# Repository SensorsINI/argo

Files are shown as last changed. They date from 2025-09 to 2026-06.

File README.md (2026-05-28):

# Argo Autonomous Sailboat

An autonomous sailboat system based on Dragonforce 65 hull, running on Orange Pi Zero 2W with ROS2. The system includes comprehensive sensor integration, autonomous navigation, and safety monitoring.

[argo freecad 3d.webm](https://github.com/user-attachments/assets/29d93eb4-6dfb-44b6-a583-b5699d12e7a1)

## News
- **May 2026:** After ignominious series of problems at CCNW with cabling, water leaks, GPS and many other issues and only 30m of actual seawater sailing, came back to INI to fix these problems. Now IMU is working, GPS is working, dashboard has map display, there are new cable glands and a new hull that has been air-pressure tested for leaks. We are ready now for water trials again.
- **Mar 2026:** Version 4 of argo PCB with bug fixes, wind sensor on separate I2C bus, and new buzzer. Version 3 of the wind sensor PCB with RGBW LED controller. See [Argo2: Robot Sailboat](https://docs.google.com/presentation/d/15X9GgjOmHowyNMNPRnduzyOgwyVcawP_Lhy54-Hc9cc/edit?usp=sharing) slides presented online at [Embodied Intelligence Conference](https://ei26.embodied-intelligence.org/) 20 March 2026.
- **Feb 2026:** Updated [wind sensor design PCB and housing](pcb/WindSensor/WindSensor-rev1/) complete. 3D parts for wind sensor I2C cable and mast step up completed and printed.
- **Jan 2026:** [Argo main PCB version 3](pcb/argo-v9-stable/argo-v9-stable-rev3/) completed and seems fully functional with no surgery needed.
- **Aug-Dec 2025:** Intense development of new [Argo PCB](pcb/) and [ROS2 software framework](nodes/). System services developed (see [`power_control/argo_power_control.py`](power_control/argo_power_control.py) and [`launch/argo_lifecycle_manager.py`](launch/argo_lifecycle_manager.py)) along with robust [lifecycle management](launch/argo_lifecycle_manager.py) and [battery/power control](power_control/argo_power_control.py).
- **Oct-Nov 2025:** Developed first version of [Argo simulator](simulator/).  
  - See [simulator/sailboat-playground/README.md](simulator/sailboat-playground/README.md) for usage and architecture.  
  - Additional docs: [Simulation Guide](docs/SIMULATION.md), [Debug Simulation Guide](docs/README-debug-simulation.md)  

## Installation

Pick **Argo (boat)** or **Host (PC)** below. ROS 2 **must match your Ubuntu LTS**: 22.04 (Jammy) → **Humble**; 24.04 (Noble) → **Jazzy**. Use the official [ROS 2 Ubuntu (deb) install](https://docs.ros.org/en/jazzy/Installation/Ubuntu-Install-Debs.html) page that corresponds to your ROS release.

### Argo (boat — Orange Pi Zero 2W)

On the robot, the stack targets **Ubuntu 22.04–based** Armbian and **ROS 2 Humble**. Bring up I²C/UART/PWM overlays, the radio/servo kernel module, Python dependencies, systemd services, and power control as described in the [launch](launch/) tree.

```bash
cd ~/argo   # or your clone path
sudo apt update && sudo apt upgrade -y
# Install ROS 2 Humble (.deb), then in each shell you use for builds:
#   source /opt/ros/humble/setup.bash

make install-all          # Python deps + optional hardware (see Makefile / messages)
make install-argo-cli
source ~/.bashrc
make -C launch install    # install systemd units; enable per docs
```

#### First-time SD card and hardware bring-up

**1. Flash Orange Pi OS** using Orange Pi Imager or equivalent.

**2. Initial system setup**

```bash
sudo apt update && sudo apt upgrade -y
sudo apt install python3-pip python3-dev build-essential
sudo apt install i2c-tools device-tree-compiler git
sudo apt install ros-humble-desktop
```

**3. Clone repository**

```bash
cd /home/orangepi
git clone https://github.com/SensorsINI/argo.git
cd argo
```

**4. Python and ROS helpers**

```bash
make install-python-deps   # requirements.txt on the boat
# If needed:
sudo apt install python3-rclpy python3-std-msgs python3-geometry-msgs
```

**5. Hardware configuration**

Edit `/boot/orangepiEnv.txt` and add overlays:

```
overlays=pi-i2c0 disable-uart0 ph-uart5 pi-pwm2 pi-pwm4
user_overlays=argo_radio_servo_overlay
```

Build and load the PWM capture module:

```bash
cd ~/argo/nodes/pwm_capture_module
make all
sudo modprobe argo_radio_servo_module   # or reboot
```

Add your user to hardware groups:

```bash
sudo usermod -a -G i2c,dialout $USER
# log out and back in
```

**6. Verify**

```bash
sudo i2cdetect -y 0
lsmod | grep argo
ls -la /sys/kernel/argo_radio_servo/
sudo cat /dev/ttyS5
```

**7. CLI and services**

```bash
make install-argo-cli && source ~/.bashrc
make -C launch install
sudo systemctl daemon-reload
sudo systemctl enable argo_launch.service
```

### Host (simulation, Foxglove, remote monitoring)

Use this on a **laptop or workstation** for **local simulation** (`asim`), **Foxglove Studio** (same Wi‑Fi, VPN, or SSH tunnel), log playback, and shore-side scripts. The boat still runs ROS 2 on the Orange Pi; your host subscribes/records like any ROS 2 client. **LoRa** is a boat link—the monitoring machine uses normal network ROS 2 or recorded bags unless you run a separate LoRa gateway stack.

**Prerequisites:** Ubuntu **22.04** or **24.04** (see mapping to Humble/Jazzy above), `git`, `make`, `sudo`, and network access for `apt`.

**One-shot bootstrap (Ubuntu 22.04 or 24.04):**

```bash
cd /path/to/argo
make host-setup
source ~/.bashrc                     # reload Argo dotfiles in this terminal (or open a new tab)
# Dotfiles auto-source the first ROS found under /opt/ros (jazzy, iron, humble, rolling) when ROS_DISTRO is unset.

source .venv/bin/activate            # optional; pip tooling (argcomplete, pyglet, …)
asim
```

If a command in **this** terminal cannot find `rclpy` or `ros2` right after `host-setup`, the ROS underlay is not loaded yet: run `source ~/.bashrc` (as above), or explicitly `source /opt/ros/humble/setup.bash` / `source /opt/ros/jazzy/setup.bash` matching your install.

`make host-setup` **refuses to run on Orange Pi** (use `make install-all` on the boat). It:

- Adds **`/etc/apt/sources.list.d/ros2-latest.list`** only if no file already references **packages.ros.org/ros2/ubuntu** (avoids a second `Signed-By` if you installed ROS 2 from the official doc first)  
- Installs **`ros-<distro>-ros-base`** when `/opt/ros/<distro>` is absent (Jammy → `humble`, Noble → `jazzy`, or override with `ROS_DISTRO=`)  
- Runs **`make install-deps`** (single `apt-get update`, then Argo’s ROS .deb set, Foxglove bridge, MCAP storage)  
- Runs **`make setup-venv`** (creates `.venv` with **uv** if available, otherwise `python3 -m venv`, and installs **`requirements-host.txt`**) then **`make install-python-deps`** (same host requirements file again into `.venv`—idempotent on a PC)  
- Runs **`make install-argo-cli`** and **`make submodule-init`** (`install-argo-cli` appends **`source <repo>/dotfiles/bashrc`** to **`~/.bashrc`**; that file auto-sources **`/opt/ros/<distro>/setup.bash`** when **`ROS_DISTRO`** is not already set)  

**Tab completion (optional):** Global argcomplete is **not** installed automatically on every shell (keeps login fast). After `host-setup`, run once: `activate-global-python-argcomplete3 --user` or `activate-global-python-argcomplete --user`, or see [dotfiles/README.md — Tab Completion Setup](dotfiles/README.md#tab-completion-setup).

Force a distro explicitly, e.g. on non-LTS or mixed images:

```bash
make host-setup ROS_DISTRO=jazzy
```

If **`apt-get update`** reports **conflicting Signed-By** for `packages.ros.org/ros2/ubuntu`, you have two ROS 2 source files—keep one. For example, if you already used the official installer, remove Argo’s duplicate and refresh: `sudo rm -f /etc/apt/sources.list.d/ros2-latest.list && sudo apt-get update`.

`install-ros2-apt-repo` checks for an existing ROS 2 source with **`sudo grep`** because some `sources.list.d` entries are **root-only**; without that, Make could miss your working repo and add a second file.

**Foxglove:** with ROS sourced on the machine that runs the bridge, start `ros2 run foxglove_bridge foxglove_bridge` and connect from [Foxglove Studio](https://foxglove.dev/) to `ws://<that-host-ip>:8765`.

### Makefile targets and shell aliases (reference)

- `make host-setup` — **host-only** full bootstrap (see above)  
- `make install-deps` — ROS packages for the current `ROS_DISTRO` (Foxglove, MCAP, …)  
- `make install-python-deps` — robot uses `requirements.txt`; host uses `requirements-host.txt` (prefers `.venv` if present)  
- `make install-hardware` — PWM module (boat)  
- `make install-all` — boat-oriented dependency + hardware path  
- `make -C launch …` — lifecycle systemd helpers  

After `make install-argo-cli`, common aliases include `al` / `aq` / `ars` (services), `as` / `asq` (status), `asim` (local sim), `ar` / `ac` (recording), `alog`, `ah`. Run `make help` and see [dotfiles/](dotfiles/).

## System Overview

The Argo system consists of multiple ROS2 nodes that work together to provide autonomous sailing capabilities:

- **Sensor Nodes**: GPS (u-blox NEO-M9N), IMU ([Adafruit BNO085](https://www.adafruit.com/product/4754)), Wind sensors (3x Sensirion SDP3x), Battery/Water monitoring
- **Control Interface**: PWM capture for radio control and servo output  
- **Autonomous Control**: Navigation and sail trimming algorithms
- **Safety Systems**: Manual override, battery monitoring, water intrusion detection

### Demo Video
See the Argo autonomous sailboat in action at the 2024 CCNW (before current waterproofing and PCB developements): [Argo Sailboat Demo](https://youtu.be/tjC1262BsCY?si=1GFPk1QcOqpzw8h2)

Argo Autonomous Sailboat

## Hardware Platform
The main PCB design for Argo is available in the [pcb/](pcb/) folder. The latest board version is [rev4](pcb/argo-v9-stable/argo-v9-stable-rev4/), which contains the current sailboat control and sensor interface design.

- **Orange Pi Zero 2W** (Allwinner H618 SoC)
- **GPS**: u-blox NEO-M9N via UART5 (/dev/ttyS5)
- **IMU**: [Adafruit BNO085](https://www.adafruit.com/product/4754) 9-DOF Orientation IMU via I2C0 (0x4a)
- **Wind Sensor**: 3x Sensirion SDP3x differential pressure sensors via I2C0 (0x21, 0x22, 0x23). This PCB includes an RGBW LED and its I2C controller PCA9632 at individual address 0x62 (0x70 is LED All Call).  
  - **Design files:** See [`pcb/WindSensor/WindSensor-rev1/`](pcb/WindSensor/WindSensor-rev1/) directory for full hardware schematics, layout, and BOM.
- **ADC**: MAX11612 for battery/water sensing via I2C0 (0x34)
- **Environment**: SHT45 temperature/humidity via I2C0 (0x44)
- **PWM I/O**: Custom kernel module for radio control and servo interfaces with high impedance safety mode
- **LORA**: Long range radio based on RA-01 radio module from ai-thinker.com using SX1276 LORA chip

### Hardware Replacement and MAC Address Cloning

The Argo system is designed to handle frequent SBC hardware replacements (due to damage) while maintaining network identity. The WiFi MAC address is frozen to a consistent value (`c8:26:e2:6c:58:ba`) stored in `network/ARGO_MAC_ID.txt` and committed to git. This ensures:

- **Network Stability**: Same MAC address across hardware changes maintains network access (uzh-iot, ZeroTier, tobi-wlan)
- **SD Card Portability**: Same SD card works seamlessly with different SBC hardware
- **Automatic Configuration**: Run `make freeze-mac-address` after hardware replacement to restore network identity

See [Network Improvements Documentation](network/README.md#mac-address-cloning-hardware-replacement) for details.

### Servo Control Hardware

The Argo system uses a shared control circuit design that allows both radio control and autonomous software control of servos through a fail-safe high impedance switching mechanism:

#### Stock DF65 V6 (2018) Servo Configuration
- **Sail Winch Servo**: Joysway #880545
  - Type: Standard sail winch servo with high-precision plastic gears
  - Operating voltage: 4.8V to 6.0V
  - PWM frequency: 1520μs/50Hz
  - **Input impedance: 12kΩ** (measured)
  - **Circuit resistor: 3.3kΩ** (optimized for proper signal level)

- **Rudder Servo**: Joysway #881504  
  - Type: Digital metal gear servo
  - Operating voltage: 4.8V to 6.0V
  - PWM frequency: 1520μs/330Hz
  - **Input impedance: 400kΩ** (measured)
  - **Circuit resistor: 10kΩ** (standard value works well)

#### Shared Control Circuit Design
The hardware implements a fail-safe shared control circuit where:

1. **High Impedance Safety Mode**: When PWM outputs are disabled (high impedance), radio control signals pass through resistors directly to servo inputs
2. **Software Control Mode**: When PWM outputs are enabled, software generates servo control signals
3. **Voltage Divider Considerations**: Resistor values are optimized based on servo input impedance:
   - Sail servo: 3.3V × (12kΩ / (3.3kΩ + 12kΩ)) = 2.6V (adequate signal level)
   - Rudder servo: 3.3V × (400kΩ / (10kΩ + 400kΩ)) = 3.2V (excellent signal level)

#### GPIO Pin Assignments (Orange Pi Zero 2W)
- **PI11 (Pin 7)**: Radio Rudder Input - GPIO input with interrupt capability
- **PI13 (Pin 26)**: Radio Sail Input - GPIO input with interrupt capability  
- **PI12 (Pin 33)**: Servo Rudder Output - PWM2 channel, high impedance when disabled
- **PI14 (Pin 16)**: Servo Sail Output - PWM4 channel, high impedance when disabled

This design ensures **radio control always works** when software is not running, providing maximum safety for autonomous sailboat operation.

## ROS2 Software Architecture
```mermaid
flowchart TB
  subgraph OUTPUTS[Output Nodes]
    RSR[rudder_sail_radio primary actuation output]
    LORA[lora long range communications]
  end

  CTRL[controller primary decision and control logic]

  subgraph SAFETY[Critical Safety Services]
    BW[battery_water critical]
    LA[launch critical]
  end

  subgraph SENSORS[Sensor Input Layer]
    GPS[gps]
    IMU[imu BNO085]
    ANEM[anem]
  end

  VR[Visualization and Recording]

  GPS --> CTRL
  IMU --> CTRL
  ANEM --> CTRL
  CTRL --> RSR

  BW --> LA
  LA --> CTRL

  CTRL --> VR

  CTRL -.-> LORA
```

### Project Organization

The Argo system follows a modular ROS2 architecture with clear separation of concerns:

**Directory Structure:**
- **`nodes/`** - Individual ROS2 nodes (Python-based sensor interfaces)
- **`launch/`** - Lifecycle management, systemd services, and launch configurations
- **`power_control/`** - Power management system (separate ROS2 package)
- **`foxglove/`** - Visualization layouts for Foxglove Studio
- **`simulator/`** - Sailboat simulation submodule (sailboat-playground)

## Other READMEs

### Core System Documentation
- [**Systemd Services Architecture**](docs/README-services.md) - Service dependencies, boot sequence, and troubleshooting
- [**Network Improvements**](network/README.md) - WiFi reconnection, MAC address cloning, and NetworkManager configuration
- [**ZeroTier VPN Setup**](docs/README_zerotier.md) - ZeroTier VPN configuration, SSH access, and network management
- [**Power Control System**](power_control/README.md) - Power button, LED control, and graceful shutdown
- [**Systemd Integration**](launch/README.md) - Launch system and lifecycle management
- [**Shutdown Fixes**](docs/SHUTDOWN_FIXES.md) - Shutdown procedure fixes and improvements
- [**LED Status Guide**](docs/ARGO_LED_STATUS_GUIDE.md) - LED status display and hatch cover indicators

### Development & Simulation
- [**Simulation System Overview**](simulator/README.md) - Sailboat simulation framework
- [**Simulation Documentation**](docs/SIMULATION.md) - Simulation setup and usage
- [**Debug Simulation**](docs/README-debug-simulation.md) - Debugging simulation issues

### Hardware & Configuration
- [**I2C Configuration**](docs/README-i2c.md) - I2C bus setup and troubleshooting
- [**LoRa (onboard ↔ shore)**](docs/README-lora-to-shore.md) - SX1276 / Waveshare hardware, link parameters, packet header
- [**IMU BNO085**](docs/README-imu-bno085.md) - C++ driver, Python bridge, calibration, `argo_bno085` service
- [**Thermal monitoring (SBC)**](docs/README-thermal-monitoring.md) - Orange Pi GPU/CPU/DDR temperature logging (`argo_thermal_monitor`)
- [**Watchdog Configuration**](docs/README-watchdog.md) - Watchdog setup for Orange Pi Zero 2W
- [**CPU Frequency Tuning**](docs/README-cpufreq-tuning-service.md) - CPU governor configuration
- [**Battery & Power Monitoring**](docs/README-battery-power.md) - Battery monitoring system
- [**Battery Panel Setup**](docs/BATTERY_PANEL_SETUP.md) - Battery panel configuration
- [**SD Card Backup**](docs/README-sd-card-backup.md) - SD card backup procedures
- [**DVFS Userspace Access**](docs/dvfs_userspace_access.md) - Dynamic voltage and frequency scaling

### Visualization & Analysis
- [**Foxglove Visualization**](foxglove/README.md) - Real-time visualization setup
- [**Foxglove Debugging**](docs/FOXGLOVE_DEBUGGING.md) - Debugging Foxglove issues
- [**Foxglove Joystick Setup**](docs/FOXGLOVE_JOYSTICK_SETUP.md) - Joystick control configuration
- [**3D Visualization**](docs/README-3d-visualization.md) - 3D visualization configuration
- [**Visualization Marker Persistence**](docs/VISUALIZATION_MARKER_PERSISTENCE.md) - Marker persistence in visualization
- [**Adding Sailing Maps**](docs/README-adding-sailing-maps.md) - Map integration guide
- [**Maps Documentation**](maps/README-maps.md) - Sailing area maps

### Remote Access & Interface
- [**Remote Desktop VNC**](docs/README_REMOTE_DESKTOP_VNC.md) - VNC remote desktop setup
- [**Web Dashboard**](docs/WEB_DASHBOARD_README.md) - Mobile-friendly web interface

### CLI & User Interface
- [**CLI Completion**](docs/CLI_COMPLETION.md) - Command-line completion setup
- [**Completion Quickstart**](docs/COMPLETION_QUICKSTART.md) - Quick start guide for CLI completion
- [**MOTD Customization**](docs/MOTD_CUSTOMIZATION.md) - Message of the day customization

### Additional Resources
- [**ROS2 Nodes**](nodes/README.md) - Node documentation and configuration
- [**Scripts**](scripts/README.md) - Utility scripts documentation
- [**Dotfiles Setup**](dotfiles/README.md) - CLI aliases and shell configuration
- [**Persistent Logging**](docs/README-persistent-logging.md) - Logging configuration

### Simulation Support

Argo includes comprehensive simulation support for development and testing:

**Local Simulation:**
- Runs simulator directly on Orange Pi
- Uses sailboat-playground or mock simulator
- Excludes conflicting hardware nodes (GPS, IMU, anemometer, radio control)
- Perfect for algorithm development and testing

**Remote Simulation:**
- Offloads CPU-intensive simulation to remote machine
- SSH tunnel for ROS2 communication
- Centralized configuration management
- Ideal for resource-constrained environments

**Quick Start:**
```bash
# Local simulation
python3 launch/argo_lifecycle_manager.py simulate_local

# Remote simulation (requires setup)
python3 launch/argo_lifecycle_manager.py simulate_remote

# Or use helper scripts (equivalent flow):
./scripts/remote_simulator_tunnel.sh &
python3 scripts/remote_simulator_launch.py &
./scripts/launch_simulator_remote.sh
```

## Directory Overview

### `launch/` - System Management & Services
Central control hub for the entire Argo system:
- **`argo_lifecycle_manager.py`** - Core lifecycle management with intelligent monitoring
- **`argo_*.sh`** - Shell scripts for start/stop/restart/status operations
- **`argo-launch.service`** - Systemd service configuration
- **`argo_gui.py`** - GTK-based status monitoring GUI
- **`argo_storage_monitor.py`** - Storage space monitoring and notifications
- **`Makefile`** - Service installation and management automation

### `nodes/` - ROS2 Node Implementations
Hardware interface and control nodes:
- **Sensor Nodes**: `gps.py`, `bno085.py`, `anem.py`, `argo_battery_water.py`, `temp_monitor.py`
- **Control Nodes**: `rudder_sail_radio.py`, `controller.py`, `record.py`
- **`pwm_capture_module/`** - Custom kernel module for radio control and servo interfaces
- **Configuration files**: `argo.yaml`, calibration data, and support utilities

### `power_control/` - Hardware Power Management
Standalone ROS2 package for power button and LED control:
- **`argo_power_control.py`** - Main power control node with GPIO management
- **Hardware Functions**: Power button monitoring, LED patterns (heartbeat/SOS), graceful shutdown
- **ROS2 Services**: LED control, system health monitoring
- **`Makefile`** - Independent installation and service management

### `pcb/` - Hardware Design Files
Custom PCB development for production-ready integration:
- **`argo-v9-stable/`** - Current stable PCB design (KiCad project files)
- **`datasheets/`** - Component specifications and reference materials
- **`orange-pi/`** - Orange Pi Zero 2W integration documentation and pin definitions
- **Bill of Materials**: Component sourcing and assembly documentation

### `foxglove/` - Real-time Visualization
Foxglove Studio integration for live system monitoring:
- **`argo_ros2.json`** - Pre-configured dashboard layout for Argo sailboat
- **`custom-argo-panel/`** - TypeScript custom panel for specialized boat visualization
- **`setup_foxglove.sh`** - Automated Foxglove Bridge configuration and startup

### `system-monitoring/` - Optional System Monitoring Services
Optional system-level monitoring services for debugging and development:
- **`Makefile`** - Installation and management of system monitoring services
- **`services/`** - Systemd service files for system monitoring
- **`scripts/`** - Monitoring scripts for boot history, memory, processes, etc.
- **Not installed by default** - Use `make install-system-monitoring` to install

**Core ROS2 Nodes:**
- **`gps.py`** - GPS receiver interface (UART5, u-blox NEO-M9N)
- **`bno085.py`** - 9-DOF Orientation IMU with sensor fusion (I2C, [Adafruit BNO085](https://www.adafruit.com/product/4754))
- **`anem.py`** - Wind sensor array (3x SDP3x pressure sensors)
- **`argo_battery_water.py`** - Power monitoring and safety systems
- **`rudder_sail_radio.py`** - Radio control input and servo output interface
- **`controller.py`** - Autonomous navigation and sail control algorithms
- **`record.py`** - Data recording management (ROS2 bag files)
- **`temp_monitor.py`** - System temperature monitoring
- **`argo_unified_simulator_bridge.py`** - Unified simulator bridge for local and remote simulation

### Node Lifecycle Management

The Argo system uses a sophisticated lifecycle management approach centered around **`argo_lifecycle_manager.py`**:

**Key Features:**
- **Real-time Monitoring**: Active process detection during startup stabilization (not static sleeps)
- **Failure Detection**: Immediate FATAL error detection and reporting from systemd journal
- **Auto-restart**: Configurable restart policies with exponential backoff
- **Graceful Shutdown**: Proper cleanup and process termination
- **Status Reporting**: Comprehensive system health monitoring

**Lifecycle Management Modes:**
```bash
python3 launch/argo_lifecycle_manager.py run             # Launch all nodes
python3 launch/argo_lifecycle_manager.py stop            # Graceful shutdown
python3 launch/argo_lifecycle_manager.py restart         # Restart all nodes
python3 launch/argo_lifecycle_manager.py status          # Show system status
python3 launch/argo_lifecycle_manager.py monitor         # Continuous monitoring
python3 launch/argo_lifecycle_manager.py simulate_local  # Local simulation mode
python3 launch/argo_lifecycle_manager.py simulate_remote # Remote simulation mode
```

**Critical Node Management:**
- **Critical Nodes**: `rudder_sail_radio.py`, `controller.py` (essential for boat operation)
- **Success Criteria**: All critical nodes + minimum 3 total nodes running
- **Failure Handling**: Intelligent restart with failure analysis and error reporting

**Startup Monitoring Pattern:**
1. **Launch Phase** - Start all node processes
2. **Detection Phase** - Wait for nodes to register (30s timeout)
3. **Stabilization Phase** - Active monitoring for failures (15s with 1s intervals)
4. **Validation Phase** - Final status check and success determination

**Systemd Integration:**
- **Service**: `argo-launch.service` runs lifecycle manager in continuous mode
- **Dependencies**: Waits for network and hardware module initialization
- **Restart Policy**: Automatic restart on failure with 5-second delay
- **Environment**: ROS2 Humble sourcing and logging configuration

## Running the System

### Manual Launch (Recommended for Testing)
```bash
cd ~/argo
source /opt/ros/humble/setup.bash
python3 launch/argo_lifecycle_manager.py run
```

### Individual Node Testing
```bash
# Test individual sensors with debug output
python3 nodes/gps.py --debug
python3 nodes/bno085.py bridge  # IMU bridge mode
python3 nodes/bno085.py status  # Check IMU health
python3 nodes/anem.py --debug
python3 nodes/argo_battery_water.py --debug
python3 nodes/rudder_sail_radio.py
python3 nodes/controller.py
```

### System Monitoring
```bash
# Monitor ROS2 topics
ros2 topic list
ros2 topic echo /battery_voltage
ros2 topic echo /anem_speed_angle_temp
ros2 topic echo /rudder_sail_radio
```

## Key ROS2 Nodes

- **`gps.py`**: GPS interface via UART5, publishes `/gps_data`
- **`bno085.py`**: [Adafruit BNO085](https://www.adafruit.com/product/4754) IMU with sensor fusion, publishes `/compass`, `/pose`, `/accel`, `/gyro`, `/imu_health`
- **`anem.py`**: Wind speed/direction from 3 pressure sensors, publishes `/anem_speed_angle_temp`
- **`argo_battery_water.py`**: Power and safety monitoring, publishes battery/water alerts
- **`rudder_sail_radio.py`**: Radio control interface and servo output
- **`controller.py`**: Autonomous navigation controller
- **`argo_unified_simulator_bridge.py`**: Unified simulator bridge for local and remote simulation
- **`lora.py`**: Long range radio node for LORA module

## Configuration Files

- **`argo.yaml`**: Main control parameters (mode, gains, etc.)
- **`argo.env`**: ROS2 environment variables for systemd services
- **`RTIMULib.ini`**: IMU calibration and sensor fusion settings

## Safety Features

- **High Impedance Safety Mode**: Servo outputs default to high impedance (PWM disabled), allowing radio control to pass through directly to servos via resistor network
- **Manual Override**: Human can take control via radio at any time, with immediate priority over autonomous control
- **Shared Control Circuit**: Fail-safe design where radio control always works when software is not running
- **Battery Monitoring**: Automatic low battery alerts (7.2V threshold)
- **Water Intrusion Detection**: Immediate alerts on water sensor activation
- **Sensor Fault Detection**: Automatic reconnection and error handling
- **Timeout Protection**: Safe defaults if communication is lost

## Data Analysis

To plot recorded bag file data, see [argo-plots-2025.py](develop/analysis/argo-plots-2025.py) (or [argo-plots-2023.py](develop/analysis/argo-plots-2023.py)).

## Troubleshooting

### Common Issues
1. **I2C Permission Errors**: Ensure user is in `i2c` group
2. **UART Permission Errors**: Ensure user is in `dialout` group  
3. **PWM Module Not Loading**: Check device tree overlay installation
4. **Sensor Not Found**: Verify I2C connections and addresses
5. **GPS No Data**: Check UART5 overlay and baud rate settings
6. **Servo Low Signal Levels**: Check servo input impedance and adjust resistor values accordingly:
   - High-power servos (e.g., winch servos) may have low input impedance (12kΩ) requiring smaller resistors (3.3kΩ)
   - Standard digital servos typically have high input impedance (400kΩ) working well with 10kΩ resistors

### Debug Commands
```bash
# Check system health
ah # show aliases
adevcheck # check for argo devices present and communicating
alog # follow argo logs - see help options
sudo i2cdetect -y 0 # check i2c bus
ros2 topic list
ros2 node list # check nodes
systemctl status argo-launch.service
```

## 2025 Development Updates

**Exciting developments are underway for 2025:**

- **Custom PCB Design**: A dedicated PCB is being designed to integrate all sensors and control systems into a single, robust board
- **Enhanced Seaworthiness**: Significant improvements to waterproofing, structural integrity, and marine-grade components for extended autonomous operation
- **Production Readiness**: Moving from prototype to production-ready autonomous sailboat system

## Documentation

For detailed technical documentation, see the [Google Doc README](https://docs.google.com/document/d/1k4FYVaFQ-n34UVE_fHvFsXmN1hixLR1Vu4WXfNnHY-0/edit?usp=sharing)

## License

BSD License - See package.xml for details

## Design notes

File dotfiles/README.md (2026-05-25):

# Argo Dotfiles

Custom bash configuration and CLI tools for Argo sailboat autonomous control system.

## Installation

```bash
cd ~/argo
make install-argo-cli
source ~/.bashrc
```

This will add `source ~/argo/dotfiles/bashrc` to your `~/.bashrc` file.

## What's Included

### Bash Aliases (`dotfiles/bash_aliases`)
Quick commands for Argo robot control:
- `al` - Start Argo nodes
- `aq` - Stop Argo nodes  
- `ars` - Restart all Argo launch nodes (`aq && al`), or one node: `ars argo_web_dashboard`
- `as` - Show Argo status
- `am` - Monitor mode
- `ar` - Start recording
- `ac` - Stop recording
- `abat` - Get battery status (formatted JSON)
- `astore` - Toggle storage rundown (enable/disable discharge to 7.6V then shut down; mode cleared on reboot)
- `ah` - Show argo help
- `ag` - Start argo GUI
- `alog` - Show argo launch logs
- `asim` - Local simulation
- `asimr` - Remote simulation

### Bash Functions (`dotfiles/bashrc`)
- `argo_status()` - Manual status check (always shows full details)
- `argo_quick_timer()` - Throttled status checking (5+ minutes since last check)

### Tab Completion (`dotfiles/.bash_completion_argo`)
Intelligent argument completion for all Argo Python scripts:

**Completion works for BOTH invocation methods:**
- `python3 script.py --<TAB>` (via global argcomplete)
- `./script.py --<TAB>` (via global argcomplete)

**Scripts with completion enabled:**
- ✅ `launch/argo_lifecycle_manager.py` - Commands: run, stop, restart, status, simulate_local, simulate_remote
- ✅ `nodes/bno085.py` - Commands: bridge, calibrate, verify, status
- ✅ `nodes/controller.py` - Full argument completion
- ✅ `nodes/anem.py` - Full argument completion
- ✅ `nodes/gps.py` - Full argument completion
- ✅ `nodes/argo_battery_water.py` - Full argument completion
- ✅ `nodes/argo_unified_simulator_bridge.py` - Full argument completion
- ✅ `nodes/rudder_sail_radio.py` - Full argument completion
- ✅ `nodes/temp_monitor.py` - Full argument completion
- ✅ `nodes/lora.py` - Full argument completion
- ✅ `power_control/argo_power_control.py` - Full argument completion

### Tmux Configuration (`dotfiles/.tmux.conf`)
Custom tmux settings for terminal multiplexing.

### Compass calibration
With BNO085, calibration is stored on the sensor itself (on-chip) and does not
use a repo-managed JSON calibration file.

## Tab Completion Setup

### How It Works
The tab completion system uses Python's `argcomplete` library:

1. **One-time hook**: Run `activate-global-python-argcomplete3 --user` (or `activate-global-python-argcomplete --user`) once so `~/.bash_completion.d/python-argcomplete.sh` exists. Optional: `ARGO_BOOTSTRAP_ARGCOMPLETE=1 bash` runs the same from `.bash_completion_argo`. The script only **sources** the hook if present so every login stays fast.
2. **Auto-Detection**: Scripts with the `PYTHON_ARGCOMPLETE_OK` marker are automatically detected
3. **Works Everywhere**: Completion works with `python3 script.py` or `./script.py`

### Requirements for Scripts
Scripts need 3 elements for completion to work:

```python
#!/usr/bin/env python3
# PYTHON_ARGCOMPLETE_OK    # Marker for global argcomplete

import argparse
import argcomplete          # After argparse import

def main():
    parser = argparse.ArgumentParser(...)
    # ... add arguments ...
    
    argcomplete.autocomplete(parser)  # Before parse_args()
    args = parser.parse_args()
```

### Adding Completion to New Scripts
Use the helper script to automatically add all required elements:

```bash
bash scripts/add_argcomplete_to_script.sh path/to/script.py
```

This will:
1. Add `# PYTHON_ARGCOMPLETE_OK` marker (line 2)
2. Add `import argcomplete` (after argparse import)
3. Add `argcomplete.autocomplete(parser)` (before parse_args())

## Testing Tab Completion

Open a new terminal (or run `source ~/.bashrc`) and try:

```bash
# Lifecycle manager commands
python3 launch/argo_lifecycle_manager.py <TAB>
# Shows: run stop restart status simulate_local simulate_remote

# IMU node commands/args
python3 nodes/bno085.py --<TAB>

# Power control options
python3 power_control/argo_power_control.py --sim<TAB>
# Completes: --simulate-double-tap --simulate-triple-tap --simulate-critical-battery --simulate-low-battery

# Direct invocation also works
./nodes/bno085.py --<TAB>
```

## Troubleshooting

### Completion Not Working

1. **Verify argcomplete is installed:**
   ```bash
   pip3 show argcomplete
   ```

2. **Check if global argcomplete is set up:**
   ```bash
   ls -la ~/.bash_completion.d/python-argcomplete.sh
   ```
   If missing, it will be auto-installed when you reload bash.

3. **Reload bash configuration:**
   ```bash
   source ~/.bashrc
   ```

4. **Verify script has the marker:**
   ```bash
   head -3 nodes/bno085.py | grep PYTHON_ARGCOMPLETE_OK
   ```

### Performance

- Completion runs only when you press TAB
- Takes ~100-200ms (acceptable for interactive use)
- Uses efficient argparse structure parsing

## PATH Configuration

The dotfiles automatically add Argo directories to PATH:
```bash
PATH="$HOME/argo/launch:$HOME/argo/nodes:$HOME/argo/scripts:$PATH"
```

This allows you to run scripts from anywhere.

## Updates and Maintenance

### Update Dotfiles
```bash
cd ~/argo
git pull  # Get latest dotfiles
source ~/.bashrc  # Reload configuration
```

### Add New Aliases
Edit `dotfiles/bash_aliases` and run:
```bash
make aliases-install
source ~/.bashrc
```

### Add Completion to New Script
```bash
bash scripts/add_argcomplete_to_script.sh path/to/new_script.py
source ~/.bashrc
```

## Files

- `bash_aliases` - Argo command aliases
- `.bash_completion_argo` - Tab completion setup
- `.bashrc` - Main bash configuration (sources other files)
- `.tmux.conf` - Tmux configuration
- (No repo-managed IMU calibration JSON with BNO085)
- `README.md` - This file

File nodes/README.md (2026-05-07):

# Argo Autonomous Sailboat - ROS2 Scripts

This directory contains the ROS2 nodes and scripts for the Argo autonomous sailboat system running on Orange Pi Zero 2W.

## System Overview

The Argo system consists of multiple sensor and control nodes that work together to provide autonomous sailing capabilities:

- **Sensor Nodes**: GPS, IMU, Wind (Anemometer), Battery/Water monitoring
- **Control Interface**: PWM capture for radio control and servo output  
- **Autonomous Control**: Navigation and sail trimming algorithms
- **Safety Systems**: Manual override, battery monitoring, water intrusion detection

## Hardware Platform

- **Orange Pi Zero 2W** (Allwinner H618 SoC)
- **GPS**: u-blox NEO-M9N via UART5 (/dev/ttyS5)
- **IMU**: [Adafruit BNO085](https://www.adafruit.com/product/4754) 9-DOF Orientation IMU via I2C0 (0x4a)
- **Wind Sensor**: 3x Sensirion SDP3x differential pressure sensors via I2C2 (0x21, 0x22, 0x23)
- **ADC**: MAX11612 for battery/water sensing via I2C0 (0x34)
- **Environment**: SHT45 temperature/humidity via I2C0 (0x44)
- **PWM I/O**: Custom kernel module for radio control and servo interfaces

### I2C Bus Configuration
**Split I2C usage**:
- **I2C bus 0**: battery/water and IMU sensors
- **I2C bus 2**: wind sensors and mast LED controller
- **I2C Bus 0 Pins**: SDA=PI6 (twi0-sda), SCL=PI5 (twi0-sck)
- **Configuration**: Enabled via `pi-i2c0` overlay in `/boot/orangepiEnv.txt`
- **Address Map**:
  - Bus 2: 0x21, 0x22, 0x23 (wind sensors), 0x62/0x70 (mast LED driver/all-call)
  - Bus 0: 0x34 (MAX11612 ADC), 0x44 (SHT45), 0x4a (BNO085 IMU)
- **Bus Speed**: Standard 100kHz I2C operation
- **Power**: 3.3V logic levels, pull-up resistors on PCB

## ROS2 Nodes

### Core Navigation Nodes

#### 1. `gps.py` - GPS Interface Node
**Purpose**: Interfaces with u-blox NEO-M9N GPS receiver over UART5

**Hardware**: 
- UART5 pins: TX=11 (PH2), RX=13 (PH3)
- Enabled via `ph-uart5` overlay in orangepiEnv.txt
- Default baud rate: 38400

**Topics Published**:
- `/gps_data` (String) - Raw NMEA sentences

**Parameters**:
- `serial_port`: /dev/ttyS5 (default)
- `baud_rate`: 38400 (default)
- `gps_frame_id`: argo_gps (default)

**Usage**:
```bash
ros2 run argo gps.py
# With debug output:
ros2 run argo gps.py --debug
```

#### 2. `bno085.py` - Inertial Measurement Unit Node
**Purpose**: Interfaces with [Adafruit BNO085](https://www.adafruit.com/product/4754) 9-DOF Orientation IMU for sensor fusion and motion data

**⚠️ IMPORTANT**: The BNO085 uses a **unique two-process architecture** (C++ driver + Python bridge) that requires systemd service management, unlike other sensor nodes. See **[README-imu-bno085.md](../docs/README-imu-bno085.md)** for complete documentation.

**Hardware**: I2C0 address 0x4a (via C++ `bno08x_driver` with Python bridge)

**Architecture**: 
- **C++ Driver** (`bno08x_driver`): Direct I2C hardware access
- **Python Bridge** (`bno085.py`): Converts to Argo topics
- **Systemd Service** (`argo_bno085.service`): **Required** for production use
- **I2C Recovery**: Automatic service restart on sensor failures

**Topics Published**:
- `/compass` (Vector3) - Magnetic field heading in µT (x, y, z=heading_deg)
- `/pose` (Vector3) - IMU orientation (x=roll, y=pitch, z=yaw in degrees)
- `/accel` (Vector3) - Linear acceleration in m/s² (x, y, z)
- `/gyro` (Vector3) - Angular velocity in rad/s (x, y, z)
- `/imu_health` (Bool) - Health status (true=healthy, false=unhealthy)

**Features**:
- **Sensor Fusion**: CEVA Hillcrest Labs SH-2 firmware for accurate orientation
- **Rotation Vector Output**: Quaternion-based absolute orientation (magnetic north reference)
- **Automatic Calibration**: On-board magnetometer, accelerometer, and gyroscope calibration
- **Health Monitoring**: Auto-recovery with 3-second data timeout detection
- **I2C Error Recovery**: Automatic systemd service restart on failures
- **Multiple Modes**: Bridge, calibration, verification, and status checking

**Quick Start** (see [README-imu-bno085.md](../docs/README-imu-bno085.md) for details):
```bash
# Install systemd service (first time)
cd ~/argo/nodes
make bno085-service-install

# Service management
make bno085-service-status
make bno085-service-restart
make bno085-service-logs

# Calibration and verification
python3 bno085.py calibrate --duration 60
python3 bno085.py verify

# Check system status
python3 bno085.py status
```

**Documentation**: See **[README-imu-bno085.md](../docs/README-imu-bno085.md)** for:
- Systemd service architecture and setup
- I2C error recovery mechanisms
- Calibration procedures
- Troubleshooting guide
- Comparison with direct I2C sensor nodes

#### 3. `anem.py` - Wind Sensor Node
**Purpose**: Calculates wind speed and direction using 3 differential pressure sensors

**Hardware**: 
- I2C2 addresses 0x21 (CCW), 0x22 (Center), 0x23 (CW)
- Based on Sensirion SDP3x directional wind meter design

**Algorithm**: Uses pressure differentials across directional ports to compute wind vector

**Topics Published**:
- `/anem_speed_angle_temp` (Vector3):
  - x: wind speed (m/s)
  - y: wind angle (degrees CW from boat front)
  - z: average temperature (°C)
- `/anem_diffpressure` (Vector3):
  - x: CCW sensor pressure (Pa)
  - y: Center sensor pressure (Pa)
  - z: CW sensor pressure (Pa)

**Usage**:
```bash
ros2 run argo anem.py
# With debug output:
ros2 run argo anem.py --debug
# With visual wind vector display:
ros2 run argo anem.py --debug_visually
```

### System Monitoring Nodes

#### 4. `argo_battery_water.py` - Power and Safety Monitoring Node
**Purpose**: Monitors battery voltage, water intrusion, and environmental conditions

**Hardware**:
- MAX11612 ADC (I2C0 0x34): AIN0=battery, AIN1=water probe, AIN2=sail current
- SHT45 sensor (I2C0 0x44): temperature and humidity

**Topics Published**:
- `battery_voltage` (Float32) - Battery voltage (V)
- `saltwater_voltage` (Float32) - Water probe voltage (V)  
- `sail_current` (Float32) - Sail winch current (A)
- `temperature` (Float32) - Temperature (°C)
- `relative_humidity` (Float32) - Relative humidity (%)
- `battery_remaining_pct` (Float32) - Battery state of charge (%)
- `battery_low_alert` (Bool) - Low battery warning
- `saltwater_alert` (Bool) - Water intrusion detection
- `humidity_alert` (Bool) - High humidity warning

**Key Parameters**:
- `battery_low_threshold_v`: 7.2V (default)
- `saltwater_alert_threshold_v`: 1.0V (default)
- `humidity_alert_threshold_pct`: 75.0% (default)
- `battery_series_cells`: 2 (for 2S LiPo, default)

**Usage**:
```bash
ros2 run argo argo_battery_water.py
# With debug terminal bars:
ros2 run argo argo_battery_water.py --debug
# ADC testing mode:
ros2 run argo argo_battery_water.py --test-adc
```

### Control and Interface Nodes

#### 5. `pwm.py` - Radio Control and Servo Interface Node
**Purpose**: Interfaces with custom kernel module for PWM capture and servo control

**Hardware Dependencies**: 
- `argo_radio_servo_module` kernel module (see pwm_capture_module/)
- Sysfs interface at `/sys/kernel/argo_radio_servo/`

**Topics Published**:
- `/rudder_sail_radio` (Vector3) - Radio control inputs (-1 to +1)
  - x: rudder position (-1=left, +1=right)
  - y: sail position (-1=in, +1=out)
- `/rudder_sail_servo` (Vector3) - Actual servo commands sent
- `/human_controlled` (Bool) - True when human has control override

**Topics Subscribed**:
- `/rudder_sail_cmd` (Vector3) - Autonomous control commands

**Features**:
- Automatic human/computer control switching
- Pulse width validation (1000-2000µs)
- Real-time servo command conversion
- Safety timeouts and neutral positioning

**Configuration**:
- `HUMAN_CONTROL_TIMEOUT_S`: 2.0 seconds
- `HUMAN_CONTROL_THRESHOLD`: 0.2 (normalized rudder deviation)

**Usage**:
```bash
ros2 run argo pwm.py
```

#### 6. `control.py` - Autonomous Navigation Controller
**Purpose**: High-level autonomous sailing control logic

**Topics Subscribed**:
- `/rudder_sail_radio` - Radio control inputs
- `/human_controlled` - Manual override status
- `/pose` - IMU orientation data (when available)

**Topics Published**:
- `/rudder_sail_cmd` (Vector3) - Autonomous control commands

**Features**:
- Parameter file hot-reloading (`argo.yaml`)
- Multiple control modes (autonomous, manual override)
- Compass-based heading control
- Configurable PID gains and limits

**Parameters** (loaded from `argo.yaml`):
- `/argo/mode`: autonomous/manual
- `/argo/rudder_gain`: Control gain multiplier

**Usage**:
```bash
ros2 run argo control.py
```

## Utility Scripts

### `load_or_reload_params.py`
Utility for dynamically loading ROS2 parameters from YAML files

### `humidity.py` 
Standalone SHT45 humidity sensor testing script

### `imu-cal.py`
IMU calibration utility for magnetometer compass calibration

### `gpio_control_example.py`
Example GPIO control script for testing hardware interfaces

### `logskip.py`
Log filtering utility for reducing verbose ROS2 output

## Configuration Files

### `argo.yaml`
Main configuration file for autonomous control parameters:
```yaml
/argo/mode: autonomous
/argo/rudder_gain: 2
```

### IMU calibration files (legacy)
Argo previously used an ICM-20948 + RTIMULib-based IMU pipeline with local
calibration files. The current IMU stack is BNO085 (`nodes/bno085.py` + C++
driver) and calibration is handled on-chip.

## Launch and Deployment

### ROS2 Launch (Recommended)
The system is designed for ROS2 but launch files are being migrated from ROS1. Current manual startup:

```bash
# Start individual nodes (development only)
ros2 run argo gps.py &
python3 ~/argo/nodes/bno085.py bridge &   # IMU bridge (driver normally launched via systemd)
ros2 run argo anem.py &
ros2 run argo argo_battery_water.py &
ros2 run argo pwm.py &
ros2 run argo control.py &
```

### Legacy ROS1 Launch Files
The `../launch/` directory contains ROS1 launch files that are being migrated:
- `argo.launch` - Main system launch file (ROS1 format)
- `argo-launch.service` - Systemd service for automatic startup

## Dependencies

### System Packages
```bash
sudo apt update
sudo apt install python3-pip python3-dev build-essential
sudo apt install i2c-tools device-tree-compiler
sudo apt install ros-humble-desktop  # ROS2 Humble
```

### Python Dependencies
```bash
pip3 install -r requirements.txt
```

Key packages:
- `rclpy` - ROS2 Python client library
- `smbus2` - I2C communication
- `pyserial` - Serial communication
- `numpy` - Numerical computations
- `tqdm` - Progress bars (optional)
- `matplotlib` - Plotting (optional)

### Hardware Setup
1. **Enable I2C and UART overlays** in `/boot/orangepiEnv.txt`:
   ```
   overlays=pi-i2c0 disable-uart0 ph-uart5 pi-pwm2 pi-pwm4
   user_overlays=argo_radio_servo_overlay
   ```
   Note: `pi-i2c0` configures bus 0 on PI5/PI6; v4 also uses bus 2 on header pins 27/28 (SDA.2/SCL.2) for wind/mast devices.

2. **Install PWM capture module** (see `pwm_capture_module/README.md`)

3. **I2C device verification**:
   ```bash
   sudo i2cdetect -y 0
   # Should show: 34 (ADC), 44 (humidity), 4a (BNO085 IMU)
   sudo i2cdetect -y 2
   # Should show: 21 22 23 (wind), 62 70 (mast LED driver)
   ```

## Debugging and Testing

### Individual Node Testing
Each node can be run standalone with debug output:
```bash
ros2 run argo <node_name>.py --debug
```

### System Health Check
```bash
# Check I2C devices on bus 0 (battery/IMU sensors)
sudo i2cdetect -y 0
# Expected devices: 34 (ADC), 44 (humidity), 4a (BNO085 IMU)
# Check I2C devices on bus 2 (wind + mast LEDs)
sudo i2cdetect -y 2
# Expected devices: 21 22 23 (wind), 62 70 (mast LEDs)

# Check PWM kernel module
lsmod | grep argo
ls -la /sys/kernel/argo_radio_servo/

# Check UART GPS
sudo cat /dev/ttyS5

# Monitor ROS2 topics
ros2 topic list
ros2 topic echo /battery_voltage
```

### Common Issues

1. **I2C Permission Errors**: Add user to i2c group:
   ```bash
   sudo usermod -a -G i2c $USER
   ```

2. **UART Permission Errors**: Add user to dialout group:
   ```bash
   sudo usermod -a -G dialout $USER
   ```

3. **PWM Module Not Loading**: Check device tree overlay installation
4. **Sensor Not Found**: Verify I2C connections and addresses
5. **GPS No Data**: Check UART5 overlay and baud rate settings

## Development Workflow

1. **Test individual sensors** using standalone debug modes
2. **Verify ROS2 topics** are publishing correctly
3. **Check parameter loading** from argo.yaml
4. **Monitor system health** via battery and environmental sensors
5. **Test manual override** functionality via radio control
6. **Validate autonomous control** in safe test environment

## Safety Features

- **Manual override**: Human can take control via radio at any time
- **Battery monitoring**: Automatic low battery alerts
- **Water intrusion detection**: Immediate alerts on water sensor activation
- **Sensor fault detection**: Automatic reconnection and error handling
- **Timeout protection**: Safe defaults if communication is lost
- **Pulse width validation**: Servo commands limited to safe ranges

## Future Enhancements

- **ROS2 launch files** to replace ROS1 legacy files
- **Web dashboard** for remote monitoring and control
- **Data logging** with automatic bag file recording
- **Advanced path planning** with GPS waypoint navigation
- **Machine learning** for optimal sail trimming
- **Telemetry system** for remote fleet management

This system provides a robust foundation for autonomous sailboat operation with comprehensive sensor integration, safety systems, and manual override capabilities.

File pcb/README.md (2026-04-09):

# PCB Design Files

This directory contains all the printed circuit board (PCB) design files, libraries, and documentation for the Argo autonomous sailboat project.

The design was done with KiCad version 9 stable.  
**It is important to use the stable KiCad version, not the development release, since KiCad will not open files from later versions!**  
- [Download KiCad stable here](https://www.kicad.org/download/)

## See also
Updated wind sensor design in [WindSensor](WindSensor).
## Current PCB
The current stable PCB [Argo PCB rev4](argo-v9-stable/argo-v9-stable-rev4) that will be tested at CapoCaccia 2026 is shown below, plugged into the OrangePiZero 2W. The only missing board is the GPS module, which sits on the standoffs. Note how the Ra-01 LORA module is soldered directly to the PCB to lower it to fit under the rudder winch. The white JST headers connect to water sensor, hatch power button with RGB LED, and 2S LiPo battery charger/balance cable. The large cables connect power from the LiPo battery, which sits alongside the keel/mast hull insert. The two black headers connect to the IMU on the rudder/winch servo chassis, and the wind sensor at the top of the mast. The board has a big white dual-coil power relay that completely cuts power when the boat is powered off.  The upper small black chip at lower left are the ADC that converts battery voltage, sail winch and rudder current, and water sensor voltage. The smaller chip below this is the humidity and PCB temperature sensor. The 4 large SMD caps at top left, below the inductor, are just to the left of the LiPo battery charger chip. The USB power input for charging is at lower right; it connects to the waterproof hatch USB port with a flex cable. Note how all cables exit on right because fore is the only available direction for connections; the PCB sits nestled up against the rudder insert and partly below the rudder/winch tray.

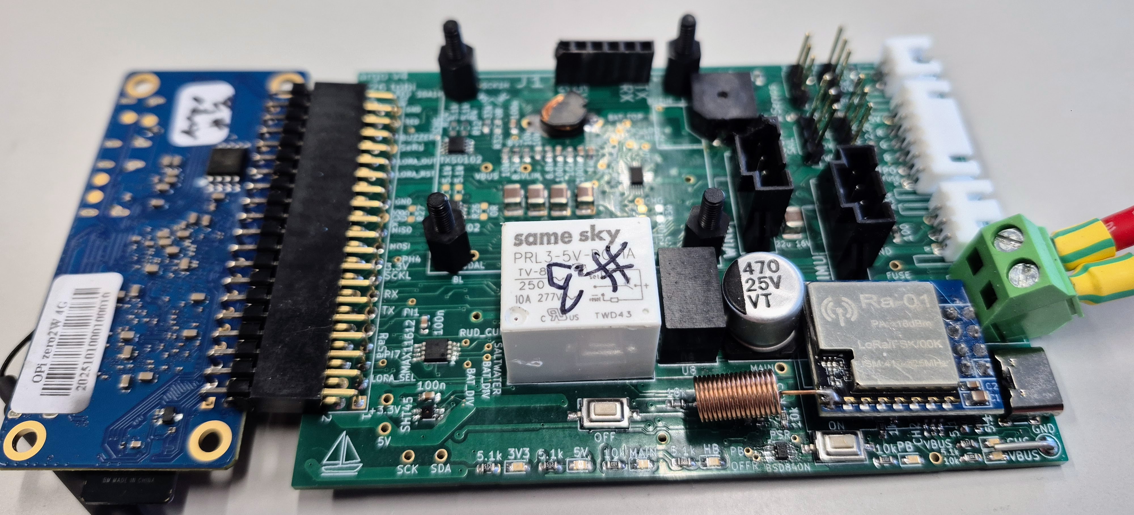
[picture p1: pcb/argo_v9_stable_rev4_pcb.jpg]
Argo v9 stable rev4 PCB with Orange Pi Zero 2W


Outstanding bugs: The rev4 PCB requires soldering a single 10k resistor to ground from the buzzer testpoint to prevent buzzer activation during boot. This resistor should be added to rev 5.

## Directory Structure

### `argo-v9-stable/`
The main PCB design files for the Argo v9 stable revision:
- **Schematic and PCB files**: KiCad project files for the main control board
- **3d-models/**: 3D model files for mechanical integration
- **Argo footprint Library.pretty/**: Custom KiCad footprint library with hand-solderable components
- **argo-v9-stable-rev4/**: Current production (rev4) manufacturing files (almopst fully functional, no modifications required except 10k pulldown on BUZZER and direct LORA soldering to PCB)
- **bom/**: Bill of Materials (BOM) files including interactive HTML BOM

### `orange-pi/`
Orange Pi Zero 2W integration files:
- **orange_pi_zero_2w.kicad_sym**: KiCad symbol for Orange Pi Zero 2W
- **orange_pi_zero_2w_pins.lib**: Pin definition library
- **3d/**: 3D models for Orange Pi Zero 2W
- **H616_Datasheet_V1.0_cleaned.pdf**: Allwinner H616 SoC datasheet
- **OPi_ZERO_2W_SCH.pdf**: Orange Pi Zero 2W schematic
- **OPi_ZERO_2W_V1_1_1A pcb layout.pdf**: PCB layout reference

## Key Components

### Main Control Board (Argo v9)
- **Microcontroller**: Orange Pi Zero 2W (Allwinner H618)
- **Power Management**: USB-C PD controller (AP33771C), power switching
- **Sensors**: 
  - GPS: u-blox NEO-M9N
  - IMU: Sparkfun BNO085
  - Wind: 3x Sensirion SDP3x differential pressure; see WindSensor folder
  - Environment: SHT45 temperature/humidity
  - Battery/Water: MAX11612 ADC
- **Interfaces**: I2C, UART, PWM capture/output, USB-C

### Design Philosophy
- **Hand-solderable components**: All footprints designed for manual assembly
- **Robust power management**: Dual coil relay, USB LiPo charging.
- **Robust I2C**: The wind sensor using different I2C bus than internal components, in case bus is shorted by water.

### Assembly Notes
- All components are hand-solderable. SMD pads have been made extra long to allow heat application and for excess solder.

## Development Tools

### KiCad Version
- **Required**: KiCad 9.0 or later
- **Footprint Library**: Custom "Argo footprint Library" with hand-solderable components

### 3D Models
- **Mechanical Integration**: 3D models have been built for all PCB components for enclosure design
- **Assembly Verification**: Use FreeCAD 1.1+ for clearance checking.

## Documentation

### Testing and Validation
- **In-Circuit Testing**: Test points provided for key signals

## Related documentation

- **[Main project README](../README.md)** — Overall system documentation
- **[Software nodes](../nodes/README.md)** — ROS2 nodes on the Orange Pi
- **[Launch](../launch/README.md)** — Startup scripts and lifecycle management
- **[Power control](../power_control/README.md)** — Battery, button, shutdown, and services; **[detailed reference](../power_control/ARGO_POWER_CONTROL_README.md)** — GPIO, hooks, and service behavior
- **[Wind sensor PCB](WindSensor/README.md)** — SDP3x wind sensor board design
- **[Orange Pi KiCad](orange-pi/README.md)** — KiCad symbol, footprint, and 3D models for the OPI header
- **[PCB v4 → v5 migration](../docs/README-argo-pcb-v4-v5-migration.md)** — Planned pin and bus changes for the next revision
- **[I2C buses](../docs/README-i2c.md)** — I2C configuration and recovery on the board
- **[Pin and bus reference](../docs/README-pins-i2c.md)** — Orange Pi 40-pin header: power, I2C, SPI, UART, PWM

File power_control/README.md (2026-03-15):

# Argo Power Control System

Intelligent power management system for Orange Pi Zero 2W with battery monitoring, safe shutdown, and emergency power preservation for manual sailing.

## Architecture Overview

The power control system consists of three main components working together:

### 1. **argo_power_control.py** - Main Control Daemon
ROS2 service that runs continuously and handles:
- **Hardware interrupt-based button monitoring** (double tap, triple tap, long press)
- **LED indicators** (heartbeat, charging status, battery warnings)
- **Battery voltage monitoring** (low battery SOS, critical battery halt)
- **Argo service control** (start/stop via double tap)
- **Recording control** (start/stop via triple tap)
- **Safe shutdown initiation** (long button press)
- **Critical battery management** (automatic halt with user confirmation)

### 2. **argo_poweroff.shutdown** - Late Shutdown Hook
systemd shutdown hook that runs during final shutdown phase:
- **Normal shutdown**: Pulses GPIO 259 HIGH to reset latching relay → cuts power
- **Critical battery halt**: Detects `/tmp/argo_critical_battery` flag → preserves power relay
- **Reboot protection**: Skips power cut during reboot operations
- **Runs after all services stop** for safe power control

### 3. **argo_power_control.service** - systemd Service
Manages the power control daemon lifecycle:
- Starts at boot with proper dependencies
- Runs as root for GPIO and shutdown control
- Restarts automatically on failure
- Sources ROS2 environment for service calls

### 4. **argo_boot_indicator.py** - Early Boot LED Indicator (Optional)
One-shot systemd service that provides early visual feedback during boot:
- **Runs at sysinit.target**: Very early in boot sequence (~15 seconds after power-on)
- **Brief GREEN LED flashing**: 5 quick flashes to indicate boot is proceeding
- **Releases GPIO immediately**: Ensures power control service can claim GPIO cleanly
- **Purpose**: Provides visual feedback during the ~30-45 second boot delay before main heartbeat starts

## Boot Timing Observations

On Orange Pi Zero 2W, the boot sequence timing is:
1. **~15 seconds**: System initialization, boot indicator flashes GREEN LED (if enabled)
2. **~30-45 seconds additional delay**: ROS2 services and dependencies starting
3. **~45 seconds total**: Main power control heartbeat becomes visible

The boot indicator service provides early feedback during this long boot sequence, reassuring users that the system is booting properly even though the main heartbeat takes nearly a minute to appear.

## Hang diagnosis (no logs, LEDs not updating)

If the service shows as running but there is no ongoing log output and power-button LEDs do not update:

1. **Run the diagnostic script** (uses `/proc` to sample syscalls; no strace required):
   ```bash
   bash power_control/diagnose_power_control_hang.sh
   ```
   With sudo you get full syscall info; without sudo you still get tee state and instructions.

2. **Trace the process** (recommended to see where it blocks):
   ```bash
   sudo apt install -y strace
   PID=$(pgrep -f "python3.*argo_power_control\.py" | head -1)
   # Use readlink to get the Python PID, not bash: for p in $(pgrep -f "argo_power_control\.py"); do readlink -f /proc/$p/exe 2>/dev/null | grep -q python && PID=$p && break; done
   sudo strace -p $PID -f 2>&1
   ```
   Run for 10–15 seconds then Ctrl+C. Look for threads stuck in the same syscall (e.g. `futex`, `epoll_pwait`, or `read`/`write` on a fd).

3. **Interpretation**: Tee in `read` means the pipe is empty—Python is not writing. So the process is stuck before producing log output (e.g. in a callback or in `_check_network_status` / WiFi check). If you temporarily remove `|& tee -a ...` from the service `ExecStart` and log only to the journal, you can confirm whether the problem is the pipeline or the Python process.

## Hardware Configuration (Rev3 PCB)

### GPIO Pin Assignments
- **PI3 (pin 40, GPIO 259)**: `POW_OFF` - Output pulse to relay RESET coil (active HIGH)
- **PH0 (pin 8, GPIO 224)**: `POW_BUT` - Power button input (active HIGH when pressed)
- **PH4 (pin 18, GPIO 228)**: Green LED in power button (ACTIVE_HIGH - NFET control: HIGH = ON, LOW = OFF)
- **PI1 (pin 12, GPIO 257)**: Blue LED in power button (active LOW - cathode control)
- **PI16 (pin 37, GPIO 272)**: Red LED for SOS warnings (active LOW - cathode control)
- **PC12 (pin 36, GPIO 76)**: `!CHARGING` from MP2672GD (LOW = charging active)
- **PH9 (pin 26, GPIO 233)**: `!ACOK` from MP2672GD (LOW = AC power present)

## Power Circuit Design

### Latching Relay System (PRL3-5V-DC-1A)
- **SET coil**: Activated by power button press → latches relay ON
- **RESET coil**: Activated by GPIO 259 HIGH pulse → unlatches relay OFF
- Magnetic latching maintains state without continuous power

### Power Distribution
1. **Battery** (2S LiPo, ~8.4V fully charged) → **7A Fuse** → **Latching Relay**
2. **Relay Output (MAIN)** powers:
   - **5V Traco switching regulator** → powers OrangePi Zero 2W and sensors
   - **Servos and radio** (via servo cables) for manual control
3. **OrangePi 3.3V regulator** powers:
   - SHT5-ADB1B humidity sensor
   - RA-01 SX1278 LoRa radio

### Power States
- **Relay ON**: Full system operation (computer + sensors + servos)
- **Relay OFF**: Minimal battery draw (~40µA from MP2672GD charger only)
- **Computer halted, Relay ON**: Radio control active for manual sailing

## Critical Battery Management

The system implements two-tier battery protection:

### 1. Low Battery Warning (< 7.6V)
- **Red LED SOS pattern** starts flashing
- **Desktop notification** warns user
- **System continues operating** but alerts are active
- User can return to shore or plug in charger

### 2. Critical Battery Halt (< 7.2V)

#### Production Mode (Default: `CRITICAL_BATTERY_USE_SHUTDOWN = False`)
**Purpose**: Preserve battery for manual sailing when computer can't operate

**Sequence**:
1. Battery monitoring detects voltage < 7.2V
2. Shows **30-second confirmation dialog** (timeout = automatic halt)
3. Pauses all sensor nodes to minimize power consumption
4. **Creates `/tmp/argo_critical_battery` flag file**
5. Executes `sudo halt` command
6. **Shutdown hook detects flag** → **PRESERVES power relay**
7. Computer halts, but servos remain powered for **manual radio control**

**Result**: Radio control active, PWM pins in high-impedance mode, ~50mA power draw vs ~500mA

#### Development Mode (`CRITICAL_BATTERY_USE_SHUTDOWN = True`)
**Purpose**: Normal shutdown for testing when you want full power cut

**Sequence**:
1. Battery monitoring detects voltage < 7.2V
2. Shows **30-second confirmation dialog**
3. Pauses all sensor nodes
4. **Does NOT create flag file**
5. Executes `shutdown -h now` command
6. **Shutdown hook runs normally** → **CUTS power relay**
7. Complete system shutdown with minimal battery drain

**Configuration**: Edit line ~206 in `argo_power_control.py`:
```python
CRITICAL_BATTERY_USE_SHUTDOWN = False  # Production: preserve power
CRITICAL_BATTERY_USE_SHUTDOWN = True   # Development: cut power
```

### Critical Battery Flag Mechanism
- **Flag file**: `/tmp/argo_critical_battery`
- **Created by**: `argo_power_control.py` when critical battery detected (production mode only)
- **Read by**: `argo_poweroff.shutdown` during shutdown sequence
- **Effect**: If flag exists → skip power cut, preserve relay for manual sailing 

## User Interface

### Power Button Behavior (Active HIGH)
- **Double tap** (2 quick presses within 3s): Toggle Argo service (start/stop all ROS2 nodes)
- **Triple tap** (3 quick presses within 3s): Toggle recording (start/stop rosbag recording)
- **Long press** (≥5 seconds): Initiate graceful system shutdown with power cut
- **Warning threshold** (3 seconds): Desktop notification warns to release button to cancel

### LED Indicators (Active LOW - Common Anode RGB)

#### Green LED (System Heartbeat)
- **1Hz pulse**: Normal operation, Argo service stopped
- **2Hz pulse**: Argo service running
- **3-flash pattern**: Recording active (3 quick flashes, then pause)
- **Paused**: Low or critical battery warning active

#### Blue LED (Charging Status)
- **ON**: Battery charging (charger connected and active)
- **OFF**: Not charging or AC power absent

#### Red LED (Battery Warnings)
- **Slow SOS pattern**: Low battery warning (< 7.6V)
- **Continuous during button press**: Combined with green for visual feedback

#### Both LEDs During Button Press
- **Gradual frequency increase**: 2Hz → 20Hz over 5-second threshold
- **Shows progress** toward shutdown threshold

#### Both LEDs During Shutdown
- **1Hz, 5% duty cycle**: Short blink pattern indicating shutdown in progress

## Main Files

### argo_power_control.py (~2800 lines)
**Primary control daemon with:**
- ROS2 service client for Argo control (`/argo/recording/*` services)
- Battery monitoring thread (30-second polling interval)
- Hardware interrupt-based button monitoring (efficient, low CPU)
- LED control threads (heartbeat, SOS patterns, shutdown indicators)
- Critical battery confirmation dialogs with timeout
- Desktop notification system for user feedback

**Key configuration constants** (lines 190-210):
```python
LOW_BATTERY_THRESHOLD_V = 7.6           # SOS warning threshold
CRITICAL_BATTERY_THRESHOLD_V = 7.2      # Halt threshold
CRITICAL_BATTERY_USE_SHUTDOWN = False   # Development flag
```

### argo_poweroff.shutdown (~134 lines)
**Late systemd shutdown hook:**
- Invoked during `system-shutdown` phase (after all services stopped)
- Checks `/tmp/argo_critical_battery` flag
- Mode detection: poweroff/halt vs reboot
- GPIO 259 pulse using Python gpiod or gpioset fallback
- Console and kernel log messages for visibility

### argo_power_control.service
**systemd service configuration:**
```ini
[Unit]
Description=Argo Power Control Service
After=network.target

[Service]
Type=simple
ExecStart=/bin/bash -c 'source /opt/ros/humble/setup.bash && python3 ~/argo/power_control/argo_power_control.py'
Restart=always
User=root

[Install]
WantedBy=multi-user.target
```

### Makefile
**Installation and management targets:**
- `make install_service`: Install systemd service
- `make install_shutdown_hook`: Install late shutdown hook
- `make check_deps`: Verify python3-libgpiod installed
- `make clean_power_control`: Remove all components

## Important: Why not gpio-poweroff overlay on Zero 2W?
- The Orange Pi Zero 2W uses an AXP PMIC that registers `pm_power_off` first during boot.
- When `pm_power_off` is already registered, the kernel `gpio-poweroff` driver refuses to bind and logs:
  - `poweroff-gpio: gpio_poweroff_probe: pm_power_off function already registered`
- Result: any `gpio-poweroff` DT node (including overlays) will not take effect.
- Solution: a systemd late shutdown hook claims PI3 and pulses it HIGH just before poweroff. This avoids conflicts and is reliably last.
- The shutdown hook intelligently differentiates between shutdown modes:
  - **Poweroff/Halt**: Triggers power cut sequence (PI3 HIGH pulse)
  - **Reboot**: Skips power cut to allow normal restart

## Prerequisites
```bash
# Install required packages
sudo apt-get update
sudo apt-get install python3-libgpiod libgpiod-tools python3-rclpy

# Add user to gpio group (if not running as root)
sudo usermod -a -G gpio $USER
# Then log out and back in
```

## Installation

### Full Installation (Recommended)
```bash
cd ~/argo/power_control

# Check dependencies
make check_deps

# Install and enable systemd service
make install_service enable_service

# Install shutdown hook
make install_shutdown_hook

# Verify installation
sudo systemctl status argo_power_control.service
```

### Manual Installation Steps
```bash
# 1. Install service
sudo cp argo_power_control.service /etc/systemd/system/
sudo systemctl daemon-reload
sudo systemctl enable argo_power_control.service
sudo systemctl start argo_power_control.service

# 2. Install shutdown hook
sudo cp argo_poweroff.shutdown /lib/systemd/system-shutdown/argo_poweroff
sudo chmod +x /lib/systemd/system-shutdown/argo_poweroff
```

## Testing

### Test Shutdown Hook (Safe - No Actual Shutdown)
```bash
# Test poweroff mode (should show power cut sequence)
sudo bash -x /lib/systemd/system-shutdown/argo_poweroff poweroff

# Test reboot mode (should skip power cut)
sudo bash -x /lib/systemd/system-shutdown/argo_poweroff reboot

# Test critical battery mode (should preserve power)
echo "TEST" | sudo tee /tmp/argo_critical_battery
sudo bash -x /lib/systemd/system-shutdown/argo_poweroff poweroff
sudo rm /tmp/argo_critical_battery
```

### Test Power Control Daemon
```bash
# Test mode (safe - simulates actions without executing)
sudo python3 argo_power_control.py --test-mode

# Test wall message (safe)
sudo python3 argo_power_control.py --test-wall-message

# Test desktop notifications (safe)
python3 argo_power_control.py --test-notification

# Simulate double tap (Argo service toggle)
sudo python3 argo_power_control.py --simulate-double-tap

# Simulate triple tap (recording toggle)
sudo python3 argo_power_control.py --simulate-triple-tap

# Simulate critical battery (shows confirmation dialog)
sudo python3 argo_power_control.py --simulate-critical-battery

# Simulate low battery (SOS LED pattern)
sudo python3 argo_power_control.py --simulate-low-battery
```

### Test Actual Shutdown (Requires Hardware)
```bash
# Normal shutdown (should cut power after ~3 seconds)
sync
sudo systemctl poweroff
# Watch GPIO 259 - should go HIGH briefly before power cuts

# Reboot test (should NOT cut power)
sync
sudo systemctl reboot
# GPIO 259 should remain LOW, system should reboot normally
```

## Usage

### Command Line Options
```bash
# Show help
python3 argo_power_control.py --help

# Normal operation (production)
sudo python3 argo_power_control.py

# Test mode (safe for development - no actual shutdown)
sudo python3 argo_power_control.py --test-mode

# Custom shutdown threshold
sudo python3 argo_power_control.py --threshold 3.0

# All options combined
sudo python3 argo_power_control.py --test-mode --threshold 2.0
```

### Service Management
```bash
# Check service status
sudo systemctl status argo_power_control.service

# View service logs
sudo journalctl -u argo_power_control.service -f

# Restart service
sudo systemctl restart argo_power_control.service

# Stop service
sudo systemctl stop argo_power_control.service

# Disable service
sudo systemctl disable argo_power_control.service
```

### Development Mode Configuration
To use normal shutdown (cut power) instead of halt (preserve power) on critical battery:

```bash
# Edit argo_power_control.py around line 206
CRITICAL_BATTERY_USE_SHUTDOWN = True   # Development: cuts power
CRITICAL_BATTERY_USE_SHUTDOWN = False  # Production: preserves power (default)

# Then restart service
sudo systemctl restart argo_power_control.service
```

## Troubleshooting

### Service Won't Start
```bash
# Check for errors
sudo journalctl -u argo_power_control.service -n 50

# Common issues:
# 1. ROS2 not sourced - check service ExecStart
# 2. GPIO permissions - check user is root or in gpio group
# 3. python3-libgpiod not installed - run make check_deps
```

### Button Presses Not Detected
```bash
# Check GPIO line status
gpioinfo | grep -E "(259|224|228|257|272)"

# Test button manually
gpioget gpiochip0 224  # Should be 0 when released, 1 when pressed

# Check service is running
sudo systemctl status argo_power_control.service
```

### LEDs Not Working
```bash
# Test LEDs manually
# Green LED (line 228, active LOW - 0=ON, 1=OFF)
gpioset gpiochip0 228=0  # Turn ON
gpioset gpiochip0 228=1  # Turn OFF

# Blue LED (line 257, active LOW)
gpioset gpiochip0 257=0  # Turn ON
gpioset gpiochip0 257=1  # Turn OFF

# Red LED (line 272, active LOW)
gpioset gpiochip0 272=0  # Turn ON
gpioset gpiochip0 272=1  # Turn OFF
```

### Power Not Cutting on Shutdown
```bash
# Check shutdown hook is installed
ls -la /lib/systemd/system-shutdown/argo_poweroff

# Check hook is executable
sudo chmod +x /lib/systemd/system-shutdown/argo_poweroff

# Test hook manually (safe - won't shutdown)
sudo bash -x /lib/systemd/system-shutdown/argo_poweroff poweroff

# Check GPIO 259 can be controlled
gpioset gpiochip0 259=1  # Should pulse relay reset coil
gpioset gpiochip0 259=0
```

### Critical Battery Flag Not Working
```bash
# Check flag file location
ls -la /tmp/argo_critical_battery

# Manually test flag mechanism
echo "TEST" | sudo tee /tmp/argo_critical_battery
sudo bash -x /lib/systemd/system-shutdown/argo_poweroff poweroff
# Should see message about preserving power

# Clean up test
sudo rm /tmp/argo_critical_battery
```

### ROS2 Service Calls Failing
```bash
# Check if Argo service is running
sudo systemctl status argo_launch_standard.service

# Test recording services manually
ros2 service list | grep recording
ros2 service call /argo/recording/start std_srvs/srv/Trigger

# Check ROS2 environment in power control service
sudo journalctl -u argo_power_control.service | grep ROS
```

## GPIO Quick Reference (H616)

| Function | Pin | GPIO Line | Direction | Active |
|---|-----|---|---|---|
| POW_OFF (relay reset) | 40 | 259 (PI3) | Output | HIGH |
| POW_BUT (power button) | 8 | 224 (PH0) | Input | HIGH |
| Green LED | 18 | 228 (PH4) | Output | LOW |
| Blue LED | 12 | 257 (PI1) | Output | LOW |
| Red LED | 37 | 272 (PI16) | Output | LOW |
| !CHARGING | 36 | 76 (PC12) | Input | LOW |
| !ACOK | 26 | 233 (PH9) | Input | LOW |

## Uninstall

### Full Uninstall
```bash
cd ~/argo/power_control

# Use Makefile target
make clean_power_control

# Or manually:
sudo systemctl stop argo_power_control.service
sudo systemctl disable argo_power_control.service
sudo rm /etc/systemd/system/argo_power_control.service
sudo rm /lib/systemd/system-shutdown/argo_poweroff
sudo systemctl daemon-reload
```

### Temporary Disable (Keep Files)
```bash
# Just stop and disable the service
sudo systemctl stop argo_power_control.service
sudo systemctl disable argo_power_control.service

# Re-enable later
sudo systemctl enable argo_power_control.service
sudo systemctl start argo_power_control.service
```

## References

- **ARGO_POWER_CONTROL_README.md**: Detailed implementation documentation
- **CRITICAL_BATTERY_PAUSE.md**: Critical battery pause mechanism details
- **Makefile**: All installation/management targets

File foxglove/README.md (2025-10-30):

# Foxglove Visualization Setup for Argo ROS2

This directory contains everything you need to visualize your Argo sailboat's ROS2 data in Foxglove Studio.

## Quick Start

### 1. Install rosbridge_server
```bash
sudo apt update
sudo apt install -y ros-humble-rosbridge-suite
```

### 2. Start Argo with Foxglove support
```bash
# Option A: Use the combined launch file (recommended)
ros2 launch ~/argo/foxglove/argo_with_foxglove_launch.py

# Option B: Start argo normally, then rosbridge separately
make start  # or your usual argo startup
ros2 launch rosbridge_server rosbridge_websocket_launch.xml
```

### 3. Connect Foxglove Studio
1. Open [Foxglove Studio](https://studio.foxglove.dev/) in your browser
2. Click "Open connection"
3. Select "Rosbridge (WebSocket)"
4. Enter: `ws://YOUR_ROBOT_IP:9090`
5. Find your robot's IP: `ip addr show | grep 'inet ' | grep -v '127.0.0.1'`

### 4. Load a layout
1. Click "Layout" in the top menu
2. Select "Import layout"
3. Choose one of these files:
   - `argo_layout.json` - Basic 4-panel layout
   - `argo_comprehensive_layout.json` - Full 6-panel layout

## Available Layouts

### Basic Layout (`argo_layout.json`)
- **3D Panel**: Shows GPS velocity vectors
- **GPS Panel**: Speed and course over ground
- **IMU Panel**: Accelerometer and gyroscope data
- **Wind Panel**: Wind speed, angle, and temperature

### Comprehensive Layout (`argo_comprehensive_layout.json`)
- **3D Panel**: GPS velocity visualization
- **GPS Panel**: Speed and course tracking
- **IMU Panel**: Full 6-axis IMU data
- **Wind Panel**: Wind sensor data
- **Power Panel**: Battery, current, and water monitoring
- **Control Panel**: Rudder/sail commands and radio input

## ROS2 Topics Visualized

### GPS Data
- `/gps_data` - Raw NMEA sentences
- `/gps_sog` - Speed over ground (knots)
- `/gps_cog` - Course over ground (degrees)
- `/gps_velocity` - Velocity vector (x=north, y=east, z=speed)

### IMU Data
- `/accel` - Accelerometer (x, y, z in g)
- `/gyro` - Gyroscope (x, y, z in deg/s)
- `/compass` - Magnetometer (x, y, z in µT)

### Wind Data
- `/anem_diffpressure` - Raw pressure differences
- `/anem_speed_angle_temp` - Wind speed (m/s), angle (deg), temp (C)

### Power & Environment
- `/battery_voltage` - Battery voltage
- `/battery_remaining_pct` - Battery percentage
- `/sail_current` - Sail servo current
- `/saltwater_voltage` - Water intrusion sensor
- `/temperature` - Environmental temperature
- `/relative_humidity` - Humidity percentage

### Control Data
- `/rudder_sail_radio` - Radio control input
- `/rudder_sail_servo` - Servo output commands
- `/rudder_sail_cmd` - Autonomous control commands
- `/human_controlled` - Manual override status

### Alerts
- `/battery_low_alert` - Low battery warning
- `/saltwater_alert` - Water intrusion alert
- `/humidity_alert` - High humidity warning

## Testing the Connection

Run the test publisher to verify Foxglove can receive data:
```bash
ros2 run argo ~/argo/foxglove/test_connection.py
```

You should see a "foxglove_test" topic in Foxglove with incrementing messages.

## Troubleshooting

### Connection Issues
1. **Can't connect to robot**: Check IP address and ensure rosbridge is running
2. **No topics visible**: Verify argo nodes are running (`ros2 topic list`)
3. **Layout not loading**: Check JSON file path and format

### Performance Issues
1. **Slow updates**: Reduce plot history length in Foxglove settings
2. **High CPU usage**: Disable unused panels or reduce update rates

### Common Commands
```bash
# Check if rosbridge is running
ros2 node list | grep rosbridge

# Check available topics
ros2 topic list

# Monitor a specific topic
ros2 topic echo /gps_sog

# Check rosbridge logs
ros2 launch rosbridge_server rosbridge_websocket_launch.xml --ros-args --log-level debug
```

## Customization

### Adding New Panels
1. Edit the layout JSON file
2. Add new panel configurations
3. Update the layout structure
4. Import the updated layout in Foxglove

### Modifying Existing Panels
1. Open the layout in Foxglove
2. Right-click on a panel → "Settings"
3. Modify colors, scales, or data sources
4. Save the layout for future use

## Integration with Makefile

You can add Foxglove support to your existing Makefile aliases:

```bash
# Add to your ~/.bash_aliases after running 'make aliases'
alias af='ros2 launch ~/argo/foxglove/argo_with_foxglove_launch.py'
alias afb='ros2 launch rosbridge_server rosbridge_websocket_launch.xml'
```

Then use:
- `af` - Launch argo with Foxglove support
- `afb` - Launch just rosbridge for existing argo session

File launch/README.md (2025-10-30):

# Argo Launch Directory

This directory contains all the launch scripts, systemd services, and management tools for the Argo autonomous sailboat system.

## 📁 Directory Contents

### 🚀 **Core Launch Files**

#### **ROS2 Launch System**
- **`argo_lifecycle_manager.py`** - Main ROS2 lifecycle manager that directly launches all sensor nodes and control systems
  - Dynamic node discovery from the `nodes/` directory
  - Fault-tolerant operation with partial node failure support
  - Direct node launching without intermediate launch files
  - Usage: `python3 launch/argo_lifecycle_manager.py run|stop|restart|status|monitor`

#### **Interactive Control**
- **`argo_gui.py`** - Interactive CLI GUI for real-time monitoring and control
  - Real-time ROS2 node status monitoring
  - Service control (start/stop/restart)
  - Recording control with color-coded status
  - Keystroke commands for quick control
  - Usage: `sudo python3 launch/argo_gui.py`

- **`argo_gui.sh`** - Shell wrapper for the GUI with proper environment setup
  - Ensures sudo privileges and ROS2 environment
  - Usage: `sudo ./launch/argo_gui.sh`

### 🔧 **System Management**

#### **Status and Monitoring**
- **`argo_lifecycle_manager.py`** - Main lifecycle management and status system
  - Systemd services status
  - ROS2 nodes status
  - System resources and storage
  - Usage: `python3 argo_lifecycle_manager.py status`

- **`storage_monitor.py`** - Storage space monitoring for recording
  - Calculates remaining recording hours
  - Displays storage warnings
  - Usage: `python3 storage_monitor.py`

- **`storage_notifications.py`** - GUI storage notifications
  - Desktop notifications for storage warnings
  - Used by systemd service for automated monitoring

#### **Power Control System**
- **`argo_power_control.py`** - Power control daemon for Orange Pi Zero 2W
  - GPIO-based power button monitoring
  - LED status indicators
  - Safe shutdown procedures
  - See `ARGO_POWER_CONTROL_README.md` for detailed documentation

- **`argo_power_control.service`** - Systemd service for power control
  - Starts early in boot process
  - Handles graceful shutdown with power relay control

### 📦 **Recording System**

#### **Data Recording**
- **`argo_record.sh`** - ROS2 bag recording script
  - Handles complete system recording
  - Automatic timestamped bag naming
  - Logging and cleanup on exit
  - Usage: `./launch/argo_record.sh`

### 🔔 **Notification System**

#### **Startup and Warnings**

- **`argo_terminal_warning.sh`** - Terminal warning system
  - Displays important system warnings
  - Storage and service alerts

#### **Setup Scripts**
- **`setup_gui_notifications.sh`** - GUI notification setup
  - Configures desktop notification system
  - Sets up storage monitoring notifications

- **`setup_terminal_warning.sh`** - Terminal warning setup
  - Configures terminal-based warning system

### ⚙️ **Systemd Services**

#### **Core Services**
- **`argo-launch.service`** - Main ROS2 launch service
  - Starts the complete Argo system
  - Uses `argo_lifecycle_manager.py` as entry point
  - Configured for user service (not auto-start by default)

- **Recording** - ROS2 service-based recording (no separate systemd service)
  - Records system data using `record.py` ROS2 node
  - Controlled via ROS2 services: `/argo/recording/start` and `/argo/recording/stop`
  - Depends on `argo-launch.service`
  - Manual start only

- **`argo-storage-monitor.service`** - Storage monitoring service
  - Monitors storage space and sends GUI notifications
  - Runs in GUI environment only
  - Automatic restart on failure

#### **Power Control Service**
- **`argo-power-control.service`** - Power control system service
  - Manages GPIO-based power control
  - Handles power button and LED indicators
  - Critical for safe shutdown procedures

### 🔧 **Configuration**

#### **Environment Files**
- **`argo.env`** - ROS2 environment configuration
  - Sets ROS2 version and distribution
  - Configures logging and network settings
  - Used by all systemd services

#### **Help System**
- **`argo_help.sh`** - Quick help reference
  - Lists available commands and aliases
  - Usage: `./argo_help.sh`

## 🚀 **Quick Start**

### **Manual Launch**
```bash
# Start the complete Argo system
python3 launch/argo_lifecycle_manager.py run

# Launch interactive GUI
sudo ./launch/argo_gui.sh

# Check system status
python3 launch/argo_lifecycle_manager.py status
```

### **Service Management**
```bash
# Install and start services
sudo systemctl --user link ~/argo/launch/argo-launch.service
sudo systemctl --user start argo-launch

# Check service status
sudo systemctl --user status argo-launch

# View logs
sudo journalctl --user -u argo-launch -f
```

### **Recording Control**
```bash
# Start recording
sudo systemctl --user start argo-record

# Stop recording
sudo systemctl --user stop argo-record

# Manual recording
./launch/argo_record.sh
```

## 📋 **Service Dependencies**

```
argo-launch.service
├── argo.env (environment)
└── argo_lifecycle_manager.py (main lifecycle manager)

recording (ROS2 service)
├── argo-launch.service (dependency)
├── argo.env (environment)
└── argo_record.sh (recording script)

argo-storage-monitor.service
├── storage_notifications.py (notification daemon)
└── DISPLAY environment (GUI required)

argo-power-control.service
├── argo_power_control.py (power daemon)
└── GPIO devices (hardware access)
```

## 🔧 **Installation**

### **From Project Root**
```bash
# Install all services
make install

# Install specific components
make install-argo-cli
make install_argo_power_control
```

### **Manual Installation**
```bash
# Install services
sudo systemctl --user link ~/argo/launch/argo-launch.service
sudo systemctl --user link ~/argo/launch/recording (ROS2 service)
sudo systemctl --user link ~/argo/launch/argo-storage-monitor.service

# Install power control (requires sudo)
sudo cp argo-power-control.service /etc/systemd/system/
sudo systemctl daemon-reload
sudo systemctl enable argo-power-control
```

## 🛠️ **Troubleshooting**

### **Common Issues**
1. **Service won't start**: Check logs with `journalctl --user -u <service-name> -f`
2. **Permission errors**: Ensure proper user/group permissions
3. **ROS2 not found**: Source ROS2 environment: `source /opt/ros/humble/setup.bash`
4. **GUI issues**: Ensure DISPLAY environment variable is set

### **Log Locations**
- **Service logs**: `journalctl --user -u <service-name>`
- **Recording logs**: `/tmp/argo_record.log`
- **Power control logs**: `journalctl -u argo-power-control`

### **Status Checking**
```bash
# Comprehensive status check
python3 launch/argo_lifecycle_manager.py status

# Storage monitoring
python3 launch/storage_monitor.py

# Service status
sudo systemctl --user status argo-launch argo-record argo-storage-monitor
sudo systemctl status argo-power-control
```

## 📚 **Documentation**

- **Power Control**: See `ARGO_POWER_CONTROL_README.md` for detailed power control documentation
- **Main Project**: See `~/argo/README.md` for overall project documentation
- **Makefile Help**: Run `make help` from project root for available commands

## 🔄 **Maintenance**

### **Regular Tasks**
- Monitor storage space before long recordings
- Check service logs for errors
- Update bag file cleanup (older than 7 days)
- Verify GPIO permissions for power control

### **Updates**
- Services are automatically reloaded when files change
- Use `sudo systemctl daemon-reload` after service file modifications
- Restart services after configuration changes

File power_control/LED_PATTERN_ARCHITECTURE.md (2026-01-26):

# LED Pattern Architecture Explanation

## Overview

The LED control system has two types of patterns:
1. **Main Heartbeat Pattern** - Continuous status indication (runs in `green_led_heartbeat()` thread)
2. **Special Patterns** - Override patterns (SOS, charging, shutdown) that pause the heartbeat

## Main Heartbeat Pattern

### Pattern Generation (`_generate_led_pattern()`)
- Creates a **10-character string** representing 10 slots
- Characters: `'g'` (green), `'r'` (red), `'b'` (blue), `'.'` (off)
- Example: `"ggrrrr...."` = 2 green, 4 red, 4 off slots

### Pattern Execution (`_execute_led_pattern()`)
- Executes over **10 slots**, each slot = **0.3 seconds total**
- Each slot structure:
  - **ON period**: 0.03s (10% duty cycle) - LED should be ON if pattern says so
  - **OFF period**: 0.27s (90% duty cycle) - All LEDs should be OFF
- Total cycle duration: 10 slots × 0.3s = **3 seconds**

### State Tracking
- Tracks LED states for **both ON and OFF periods** within each slot
- Total states tracked: **20** (10 slots × 2 periods each)
- Summary format (exactly 20 characters per LED, excluding the "R:"/"G:"/"B:" prefix):
  ```
  R:----r-r-r-r--------
  G:g-g-----------------
  B:--------------------
  ```
- Each pair of characters = one slot: `[ON_period][OFF_period]`
- Characters: `r`/`g`/`b` = LED ON, `-` = LED OFF
- Example for pattern "ggrrrr...." (10 slots):
  - **Green LED tracking:**
    - Slot 0: g → ON period: `g`, OFF period: `-` → `g-`
    - Slot 1: g → ON period: `g`, OFF period: `-` → `g-`
    - Slots 2-9: . → ON period: `-`, OFF period: `-` → `----------------` (16 dashes)
    - Result: `g-g-----------------` = **20 characters** (2+2+16)
  - **Red LED tracking:**
    - Slots 0-1: . → ON period: `-`, OFF period: `-` → `----` (4 dashes)
    - Slots 2-5: r → ON period: `r`, OFF period: `-` → `r-r-r-r-` (8 chars: r-, r-, r-, r-)
    - Slots 6-9: . → ON period: `-`, OFF period: `-` → `--------` (8 dashes)
    - Result: `----r-r-r-r--------` = **20 characters** (4+8+8)

## Special Patterns (Override Main Heartbeat)

These patterns run in **separate threads** and **pause the heartbeat**:

1. **SOS Pattern** (`sos_led_pattern()`)
   - Runs when: Low battery detected
   - Controls: Red LED only
   - Calls: `pause_heartbeat("low_battery")` → `resume_heartbeat()` when done

2. **Charging State Pattern** (`charge_state_led_pattern()`)
   - Runs when: AC power present and charging
   - Controls: Blue LED (duty cycle = charge percentage)
   - Calls: `pause_heartbeat("charging_state")` → `resume_heartbeat()` when done

3. **Shutdown Pattern** (`shutdown_led_pattern()`)
   - Runs when: Shutdown sequence initiated
   - Controls: All LEDs (short-long pattern)
   - Calls: `pause_heartbeat()` → heartbeat never resumes (system shutting down)

## Pattern Flow

```
Main Loop (green_led_heartbeat):
  while running:
    if heartbeat_paused:
      sleep(0.1)  # Wait for special pattern to finish
      continue
    
    pattern = _generate_led_pattern()  # "ggrrrr...."
    _execute_led_pattern(pattern)       # Execute over 10 slots (3 seconds)
    # Loop repeats
```

## Key Points

1. **Main heartbeat** generates and executes 10-slot patterns continuously
2. **Each slot** = 0.3s total (0.03s ON + 0.27s OFF)
3. **Special patterns** pause the heartbeat and take direct control
4. **State tracking** shows 20 states (10 slots × 2 periods) to detect if LEDs stay ON during OFF periods
5. **Pattern string** is 10 characters, but execution tracks 20 states (ON+OFF for each slot)

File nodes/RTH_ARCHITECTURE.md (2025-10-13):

# Return-to-Home System Architecture

## Data Flow Diagram

```
┌─────────────────────────────────────────────────────────────────────────┐
│                           SHORE SIDE                                    │
│  ┌──────────────┐                                                       │
│  │  Operator    │  Command: "return_home"                               │
│  │  (Foxglove)  │────────────────────┐                                  │
│  └──────────────┘                    │                                  │
│                                      ▼                                   │
│                              ┌──────────────┐                            │
│                              │ lora_shore.py│                            │
│                              │ (USB LoRa)   │                            │
│                              └──────┬───────┘                            │
└─────────────────────────────────────┼──────────────────────────────────┘
                                      │
                          LoRa Radio (433 MHz)
                                      │
┌─────────────────────────────────────┼──────────────────────────────────┐
│                          ARGO BOAT  │                                   │
│                              ┌──────▼───────┐                            │
│                              │   lora.py    │                            │
│                              │  (SPI/GPIO)  │                            │
│                              └──────┬───────┘                            │
│                                     │                                    │
│              ┌──────────────────────┼──────────────────────┐             │
│              │                      │                      │             │
│              ▼                      ▼                      ▼             │
│  ┌────────────────────┐  ┌──────────────────┐  ┌──────────────────┐    │
│  │/lora_connection_   │  │/lora_remote_     │  │/lora_signal_     │    │
│  │ status (Bool)      │  │ command (String) │  │ strength (Int32) │    │
│  └─────────┬──────────┘  └─────────┬────────┘  └──────────────────┘    │
│            │                       │                                    │
│            │         ┌─────────────┘                                    │
│            │         │                                                  │
│            │         │        ┌────────────┐                            │
│            │         │        │  gps.py    │                            │
│            │         │        │  (UART5)   │                            │
│            │         │        └─────┬──────┘                            │
│            │         │              │                                   │
│            │         │              ▼                                   │
│            │         │    ┌──────────────────┐                          │
│            │         │    │ /fix (NavSatFix) │                          │
│            │         │    │ - latitude       │                          │
│            │         │    │ - longitude      │                          │
│            │         │    └─────┬────────────┘                          │
│            │         │          │                                       │
│            ▼         ▼          ▼                                       │
│  ┌───────────────────────────────────────┐                              │
│  │         controller.py                 │                              │
│  │  ┌─────────────────────────────────┐  │                              │
│  │  │      BoatState                  │  │                              │
│  │  │  - shore_connected              │  │                              │
│  │  │  - last_shore_contact           │  │                              │
│  │  │  - remote_command               │  │                              │
│  │  │  - home_latitude/longitude      │  │                              │
│  │  │  - current_latitude/longitude   │  │                              │
│  │  │  - return_to_home_active        │  │                              │
│  │  └─────────────────────────────────┘  │                              │
│  │              │                         │                              │
│  │              ▼                         │                              │
│  │  ┌─────────────────────────────────┐  │                              │
│  │  │  RTH Activation Logic           │  │                              │
│  │  │  if shore_disconnected > 120s   │  │                              │
│  │  │  OR remote_command == 'rth'     │  │                              │
│  │  └──────────┬──────────────────────┘  │                              │
│  │             │                          │                              │
│  │             ▼                          │                              │
│  │  ┌─────────────────────────────────┐  │                              │
│  │  │ ReturnToHomeController          │  │                              │
│  │  │  1. bearing = get_bearing()     │  │                              │
│  │  │  2. distance = get_distance()   │  │                              │
│  │  │  3. target_heading = bearing    │  │                              │
│  │  │  4. generate_control()          │  │                              │
│  │  └──────────┬──────────────────────┘  │                              │
│  └─────────────┼──────────────────────────┘                              │
│                │                                                         │
│                ▼                                                         │
│  ┌────────────────────────────┐                                         │
│  │ /rudder_sail_cmd (Vector3) │                                         │
│  └─────────────┬──────────────┘                                         │
│                │                                                         │
│                ▼                                                         │
│  ┌──────────────────────────────┐                                       │
│  │  rudder_sail_radio.py        │                                       │
│  │  (Control Arbitration)       │                                       │
│  └─────────────┬────────────────┘                                       │
│                │                                                         │
│                ▼                                                         │
│  ┌──────────────────────────────┐                                       │
│  │  Servos (Rudder + Sail)      │                                       │
│  └──────────────────────────────┘                                       │
└─────────────────────────────────────────────────────────────────────────┘
```

## State Machine

```
┌─────────────┐
│   STARTUP   │
│  (No GPS)   │
└──────┬──────┘
       │ First GPS fix
       ▼
┌─────────────┐
│  NORMAL     │◄───────────────────┐
│  (Human)    │                    │
└──────┬──────┘                    │
       │ Human releases control   │
       ▼                          │
┌─────────────┐                   │
│  AUTONOMOUS │                   │
│  (Standard) │                   │
└──────┬──────┘                   │
       │                          │
       │ Connection lost > 120s   │
       │ OR 'return_home' cmd     │
       ▼                          │
┌─────────────┐                   │
│   RETURN    │                   │
│   TO HOME   │                   │
│   (RTH)     │                   │
└──────┬──────┘                   │
       │                          │
       │ Arrived at home          │
       │ OR 'autonomous' cmd      │
       └──────────────────────────┘
```

## Controller Selection Logic

```python
def timer_callback():
    if human_controlled:
        # Human has control - update target heading
        target_heading = current_heading
        
    else:
        # Autonomous mode
        
        # Check if RTH should activate
        if isinstance(controller, ReturnToHomeController):
            if controller.should_activate(boat_state):
                # Already in RTH mode, continue
                pass
        else:
            # Check if we need to switch to RTH
            temp_rth = ReturnToHomeController(config)
            if temp_rth.should_activate(boat_state):
                # Connection lost! Switch to RTH
                controller = temp_rth
        
        # Generate control commands
        control_cmd = controller.generate_control(boat_state)
        publish(control_cmd)
```

## RTH Navigation Algorithm

```python
class ReturnToHomeController:
    def generate_control(self, state):
        # 1. Calculate navigation parameters
        bearing_to_home = state.get_bearing_to_home()  # 0-360 degrees
        distance_to_home = state.get_distance_to_home()  # nautical miles
        
        # 2. Check arrival
        if distance_to_home < 0.05:  # 90 meters
            return ControlCommand(rudder=0.0, sail=0.0)  # Arrived!
        
        # 3. Set target heading toward home
        state.target_heading = bearing_to_home
        
        # 4. Calculate rudder command (proportional control)
        heading_error = bearing_to_home - state.compass_heading
        rudder = rudder_gain * (heading_error / rudder_full_scale)
        
        # 5. Calculate sail command (wind-aware)
        if wind_angle is not None:
            sail = wind_based_sail_position()
        
        return ControlCommand(rudder, sail)
```

## GPS Home Position Logic

```
GPS Fix Received (/fix topic)
       │
       ▼
   Is home position set?
       │
       ├─ NO ──► Set home_latitude = current_latitude
       │         Set home_longitude = current_longitude
       │         Log: "🏠 Home position set: lat, lon"
       │
       └─ YES ─► Update current_latitude = GPS latitude
                 Update current_longitude = GPS longitude
                 
Every control loop:
    - Calculate bearing_to_home using Haversine
    - Calculate distance_to_home using great circle
    - Use bearing as target_heading if RTH active
```

## LoRa Command Processing

```
Shore sends command ────► LoRa Radio ────► lora.py
                                              │
                                              ▼
                                    /lora_remote_command
                                              │
                                              ▼
                                    controller.py
                                              │
                                              ▼
                          ┌───────────────────┴───────────────────┐
                          │                                       │
                    "return_home"                          "autonomous"
                          │                                       │
                          ▼                                       ▼
            Set return_to_home_active = True      Set return_to_home_active = False
            Log bearing and distance to home      Resume normal autonomous operation
```

## Typical Operation Sequence

1. **System Start**
   - Controller starts in human control mode
   - GPS acquires fix
   - Home position set automatically
   - LoRa connection established

2. **Autonomous Operation**
   - Human releases control via radio
   - Controller uses `proportional` or `wind_aware` mode
   - LoRa sends periodic status to shore

3. **Connection Loss**
   - LoRa connection times out (120 seconds)
   - Controller detects: `shore_connected = False`
   - Automatic switch to `ReturnToHomeController`
   - Boat begins navigating toward home

4. **RTH Navigation**
   - Calculate bearing to home: 270° (West)
   - Calculate distance: 2.5 nm
   - Update heading to 270°
   - Adjust sail based on wind
   - Log progress every 10 seconds

5. **Arrival**
   - Distance < 0.05 nm (90 meters)
   - Set rudder and sail to neutral (0.0)
   - Boat drifts near starting position

6. **Connection Restored**
   - LoRa reconnects
   - Shore sends `"autonomous"` command
   - Controller switches back to normal mode
   - Resume mission

## Key Design Decisions

### Why GPS-based navigation?
- **Precise**: GPS provides accurate position data
- **Independent**: Works without shore communication
- **Standard**: Uses existing `/fix` topic from gps.py

### Why automatic home position?
- **Safe**: Always has a return point
- **Simple**: No manual configuration required
- **Persistent**: Set once at startup, used throughout mission

### Why 120-second timeout?
- **Tolerant**: Allows temporary connection loss
- **Safe**: Long enough to avoid false triggers
- **Configurable**: Can be adjusted in parameters

### Why 90-meter arrival radius?
- **GPS Accuracy**: Typical GPS error ~5-10 meters
- **Safe**: Large enough to reliably detect arrival
- **Small**: Close enough to original position

## Monitoring and Debugging

### Check RTH Status
```bash
# Monitor controller logs
ros2 topic echo /rudder_sail_cmd

# Check GPS position
ros2 topic echo /fix --field latitude,longitude

# Monitor LoRa connectivity
ros2 topic echo /lora_connection_status

# Watch distance to home (requires custom subscriber)
ros2 topic echo /control_authority
```

### Simulate RTH
```bash
# Force connection loss
ros2 topic pub /lora_connection_status std_msgs/Bool "data: false"

# Manual RTH trigger
ros2 topic pub --once /lora_remote_command std_msgs/String "data: 'return_home'"

# Check controller type
ros2 param get /controller_node controller_type
```

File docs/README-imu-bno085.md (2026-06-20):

# BNO085 IMU Integration Guide

## Overview

The Argo autonomous sailboat uses the [Adafruit BNO085](https://www.adafruit.com/product/4754) 9-DOF Orientation IMU for precise heading and motion sensing. This sensor provides superior accuracy compared to the previous ICM-20948 through on-chip sensor fusion and automatic calibration.

## Architecture

### System Overview

**IMPORTANT:** The BNO085 uses a **two-process architecture** unlike other Argo sensor nodes like `anem.py`, `gps.py`, or `argo_battery_water.py` which directly access hardware. This dual-process design requires systemd service management for production use.

```
┌─────────────────────────────────────────────────────────┐
│              Systemd Service Layer                      │
│  argo_bno085.service - Auto-restart & lifecycle mgmt   │
└──────────────────┬──────────────────────────────────────┘
                   │ manages
                   ▼
    ┌──────────────┴──────────────┐
    ▼                              ▼
┌──────────────────┐    ┌──────────────────────┐
│  bno08x_driver   │    │  bno085.py bridge    │
│  (C++ ROS2 node) │    │  (Python ROS2 node)  │
│                  │    │                      │
│ Direct I2C bus   │    │ Subscribes:          │
│ access to        │───▶│  /imu                │
│ BNO085 sensor    │    │  /magnetic_field     │
│                  │    │                      │
│ Publishes:       │    │ Publishes (Argo):    │
│  /imu            │    │  /compass            │
│  /magnetic_field │    │  /pose               │
└──────────────────┘    │  /accel              │
                        │  /gyro               │
                        │  /imu_health         │
                        └──────────────────────┘
```

### Why Two Processes?

1. **Hardware Abstraction**: C++ driver provides low-level I2C communication and SH-2 protocol handling
2. **Sensor Fusion**: On-chip BNO085 firmware requires complex binary protocol (SH-2)
3. **ROS2 Ecosystem**: Standard `bno08x_driver` is well-maintained and widely used
4. **Performance**: C++ driver handles high-frequency sensor data efficiently
5. **Reliability**: Systemd service automatically restarts both processes on I2C errors

### Comparison with Other Sensors

| Sensor Node | I2C Access | Architecture | Service Required |
|---|---|---|---|
| `anem.py` | Direct (smbus2) | Single Python process | ❌ No |
| `gps.py` | N/A (UART) | Single Python process | ❌ No |
| `argo_battery_water.py` | Direct (smbus2) | Single Python process | ✅ Yes (basic service) |
| **`bno085.py`** | **Via C++ driver** | **Two processes + systemd** | **✅ Yes (dual-process service)** |

### Systemd Service Integration

The `argo_bno085.service` systemd service is **required for production use** and provides:

- **Process Management**: Starts both C++ driver and Python bridge together
- **Auto-Restart**: Recovers from I2C errors and driver crashes (5-second delay)
- **ROS2 Environment**: Proper environment sourcing for both processes
- **Lifecycle Integration**: Status visible in `argo_lifecycle_manager.py`
- **Journal Logging**: Centralized logging via systemd journal

## Hardware Configuration

- **Sensor**: [Adafruit BNO085](https://www.adafruit.com/product/4754) 9-DOF Orientation IMU
- **Interface**: I2C bus 0 at address 0x4a
- **Protocol**: SHTP (Sensor Hub Transport Protocol) over I2C, carrying SH-2 sensor-hub commands
- **Fusion**: CEVA Hillcrest Labs SH-2 firmware for on-chip sensor fusion

## Software Components

### 1. C++ Driver (`bno08x_driver`)
- **Upstream**: [bnbhat/bno08x-ros2-driver](https://github.com/bnbhat/bno08x-ros2-driver)
- **Argo fork**: [tobidelbruck/bno08x_ros2_driver](https://github.com/tobidelbruck/bno08x_ros2_driver) (git submodule at `nodes/vendor/bno08x_driver/`)
- **Function**: Direct hardware communication via I2C and SHTP/SH-2 stack (`include/sh2/`)
- **Topics Published**:
  - `/imu` (sensor_msgs/Imu) - Quaternion orientation, gyro, accel
  - `/magnetic_field` (sensor_msgs/MagneticField) - Magnetometer data
- Launched by `bno085_driver_launcher.sh` (used by `argo_bno085.service`)

### 2. Python Bridge (`bno085.py`)
- **Location**: `nodes/bno085.py`
- **Function**: Converts C++ driver output to Argo format
- **Topics Subscribed**: `/imu`, `/magnetic_field`
- **Topics Published**: See [Bridge published topics (Argo)](#bridge-published-topics-argo) for units, frames, and conventions.

## Quick Start

### 1. Build and Install Service (First Time Setup)
```bash
cd ~/argo/nodes

# Build the C++ driver and install systemd service
make bno085-service-install

# This will:
# - Initialize and build the bno08x_driver submodule
# - Install argo_bno085.service to systemd
# - Enable auto-start on boot
# - Start the service immediately
```

### 2. Verify Operation
```bash
# Check service status
make bno085-service-status
# or: systemctl status argo_bno085.service

# Check topics are publishing
ros2 topic list | grep -E '(imu|compass|pose)'

# Monitor compass heading
ros2 topic echo /compass

# Check health status
ros2 topic echo /imu_health

# View live logs
make bno085-service-logs
# or: journalctl -u argo_bno085.service -f
```

### 3. Service Management
```bash
# Start/stop/restart service
make bno085-service-start
make bno085-service-stop
make bno085-service-restart

# Check status in lifecycle manager
python3 ~/argo/launch/argo_lifecycle_manager.py status
# Should show: 🧭 BNO085 IMU: 🟢 RUNNING

# Uninstall service (if needed)
make bno085-service-uninstall
```

### 4. Development/Testing (Without Service)
```bash
# For development, you can run manually:
make bno08x-launch-full

# Or manually:
bash -c "source /opt/ros/humble/setup.bash && \
         source ~/argo/nodes/argo_bno08x_driver_workspace/install/setup.bash && \
         ros2 run bno08x_driver bno08x_driver --ros-args --params-file vendor/bno085_i2c_argo.yaml &"
sleep 3
python3 bno085.py bridge
```

## Unified Tool Usage

All BNO085 functionality is consolidated into a single tool: `bno085.py`

### Commands

#### `bridge` (default mode)
Runs as a persistent ROS2 node for normal operation:
```bash
bno085.py bridge
# or simply:
bno085.py
```

#### `status`
Check system health and connectivity:
```bash
bno085.py status
```

#### `calibrate`
Interactive calibration with real-time guidance:
```bash
# Standard 2-minute calibration
bno085.py calibrate

# Custom duration (5 minutes)
bno085.py calibrate --duration 300
```

#### `verify`
Verify sensor output matches datasheet specifications:
```bash
# Continuous verification
bno085.py verify

# Verify for specific duration
bno085.py verify --duration 60
```

### Bash Completion
Enable tab completion for commands and options:
```bash
eval "$(register-python-argcomplete bno085.py)"
```

## Configuration

### Automatic I2C Bus Configuration

**IMPORTANT**: The BNO08x driver submodule C++ source may default to `/dev/i2c-7`, but Orange Pi Zero 2W uses `/dev/i2c-0`. Argo sets the bus in **`nodes/vendor/bno085_i2c_argo.yaml`** (`i2c.bus: "/dev/i2c-0"`). The Makefile **patches the C++ default** to i2c-0 during `make bno08x-build` if upstream still ships i2c-7.

**Manual verification:**
```bash
grep 'bus:' vendor/bno085_i2c_argo.yaml
# Should show: bus: "/dev/i2c-0"
```

**Why C++ patching?**
- **Submodule is upstream**: Can't commit hardware-specific changes without forking
- **YAML is authoritative for Argo**: Single file `bno085_i2c_argo.yaml` used by systemd, Makefile, and launch
- **Fresh install support**: Ensures new clones work after `make bno085-service-install`

### Driver Configuration

The BNO08x C++ driver is configured via **`nodes/vendor/bno085_i2c_argo.yaml`** (single source of truth).

**File Location:** `nodes/vendor/bno085_i2c_argo.yaml`

**Current Configuration:**
```yaml
bno08x_ros:  # ⚠️ IMPORTANT: Namespace must match node name (not bno08x_driver)
  ros__parameters:

    frame_id: "bno085"

    i2c:
      enabled: true
      bus: "/dev/i2c-0"
      address: "0x4A"

    publish:
      magnetic_field:
        enabled: true
        rate: 1    # 1 Hz
      imu:
        enabled: true
        rate: 5    # 5 Hz — stable on shared bus 0; increase only if needed
```

**Configuration Options:**
- **`frame_id`**: ROS2 frame ID for the IMU (Argo default: `"bno085"`)
- **`i2c.bus`**: I2C device path (default: `/dev/i2c-0` for Orange Pi Zero 2W)
- **`i2c.address`**: BNO085 I2C address (default: `"0x4A"`)
- **`publish.magnetic_field.rate`**: Magnetometer publish rate in Hz (1–100, default: 1)
- **`publish.imu.rate`**: IMU data publish rate in Hz (1–400, default: 5 for shared bus 0)
- **`watchdog.timeout_ms`**: C++ driver reset if no sensor reports (optional; see yaml comments)

**⚠️ CRITICAL: YAML Namespace Configuration**

The YAML file **must** use `bno08x_ros:` as the top-level namespace, **not** `bno08x_driver:`. This is because the ROS2 node name is `bno08x_ros` (defined in the C++ source).

```yaml
# ✅ CORRECT
bno08x_ros:
  ros__parameters:
    ...

# ❌ WRONG - Parameters will be ignored!
bno08x_driver:
  ros__parameters:
    ...
```

If the wrong namespace is used, the driver will ignore your configuration and use default values (100Hz for both rates).

**Usage:**
This configuration file is automatically loaded by:
- Makefile targets (`bno08x-launch`, `bno08x-launch-full`)
- Systemd service (`argo_bno085.service`)
- Direct `ros2 run` commands with `--params-file` argument

**Customization:**
To change publish rates or other settings:
1. Edit `vendor/bno085_i2c_argo.yaml` (ensure `bno08x_ros:` namespace)
2. Restart the service: `make bno085-service-restart`
3. Verify rates in logs: Look for "IMU Rate: 5" and "Magnetic Field Rate: 1"

## Data Format

### Rotation Vector (Quaternion)
The BNO085 provides orientation as a quaternion (w, x, y, z) representing the Rotation Vector from datasheet section 2.2.4:

```yaml
# /imu topic (from C++ driver)
orientation:
  x: -0.113
  y: -0.301
  z: 0.839
  w: 0.439  # Rotation Vector quaternion
```

### Compass Heading
The bridge derives a yaw angle from the C++ driver’s `sensor_msgs/Imu` quaternion (Euler Z after the configured mount offset). That value is published as **compass heading** on `/compass` and, after a convention conversion, as **ENU math yaw** on `/pose` (see below).

```yaml
# /compass topic (from bridge) — compass convention on z
x: 0.0
y: 0.0
z: 127.93  # degrees, clockwise from north, range [0, 360)
```

## Bridge published topics (Argo)

All Argo-facing topics below are published by `bno085.py` in **bridge** mode. They originate from the C++ driver’s `/imu` stream (rotation vector fusion on the BNO085), except `/imu_health`, which is generated in the bridge.

| Topic | Message type | Source | `x` / `y` / `z` meaning | Range / convention |
|---|---|---|---|---|
| `/compass` | `geometry_msgs/Vector3` | Quaternion → Euler yaw + `yaw_offset_deg` | **Heading (compass):** `z` only; `x`,`y` set to `0`. | `z ∈ [0, 360)` **degrees**, **clockwise from north**: 0° = north, 90° = east, 180° = south, 270° = west. |
| `/pose` | `geometry_msgs/Vector3` | Same fused yaw as `/compass`, then converted for Argo TF/controller | **ENU yaw (mathematical):** `z` only; `x`,`y` set to `0`. | `z ∈ [0, 360)` **degrees**, **counter-clockwise from east** when viewed from above: 0° = east, 90° = north, 180° = west, 270° = south. Conversion: `pose.z = (450 - compass_z) % 360` (same as `argo_unified_simulator_bridge`). |
| `/accel` | `geometry_msgs/Vector3` | `Imu.linear_acceleration` (m/s²) scaled by `1/9.81` | Approx. **g** in driver axes; `x`,`y` optionally rotated with `apply_axis_rotation` and mount offset. | Roughly -1 to 1 g per axis at rest (gravity on one axis); not SI m/s² on the wire. |
| `/gyro` | `geometry_msgs/Vector3` | `Imu.angular_velocity` (rad/s) → degrees/s | **deg/s** about IMU X, Y, Z. | Magnitude depends on motion; signs follow right-hand rule around each axis. |
| `/imu_health` | `std_msgs/Bool` | Bridge timer + IMU freshness | `data`: sensor path healthy. | `true` / `false`. |

**Why `/compass` and `/pose` differ:** Controllers and dashboards consume **compass** heading (wind and navigation are stated in compass degrees). `argo_transform_publisher`, Foxglove ENU views, and the simulator bridge expect **`/pose.z` as ROS-style yaw in the horizontal plane** (east-referenced, CCW positive), so the bridge publishes the conversion on `/pose` only.

**Legacy rosbag2 recordings:** Bags recorded before `/pose` carried math yaw may store compass values on `/pose.z`. That skews TF and 3D playback. Rewrite bags with:

`python3 scripts/fix_rosbag_pose_legacy_compass.py INPUT_BAG_DIR OUTPUT_BAG_DIR`  
(use `--dry-run` first; `--force` overwrites an existing output folder). That script **only** rewrites `/pose`; it does **not** change recorded `/tf` or recorded visualization markers (see script docstring).

To **re-record** playback with live visualization and transforms into a new bag, the launch file lives under **`scripts/argo_bag_rerecord.py`** (not under `launch/`). Typical invocation from the Argo repo root with ROS 2 sourced:  
`ros2 launch ./scripts/argo_bag_rerecord.py input_bag:=bags/your_bag output_bag:=your_bag_with_viz`  
or run **`scripts/argo_rerecord_bag.sh`**, which calls that launch file for you.

See **[README-bagfiles.md](README-bagfiles.md)** for all bag tools (narration merge, backup, Foxglove playback, etc.).

## Health Monitoring

The bridge publishes `/imu_health` (std_msgs/Bool) for lifecycle management:

### Health States
- **✅ HEALTHY (`data: true`)**: Sustained `/imu` stream — not stale, past post-gap cooldown, stable for ~5 s (see tuning constants in `bno085.py`)
- **❌ UNHEALTHY (`data: false`)**: No data, stale stream, post-gap cooldown, or stream not yet stable

### Implementation
- **Initialization**: Starts unhealthy until stream meets stability criteria
- **Data Reception**: Updates on each `/imu` message from C++ driver
- **Periodic Check**: 1 Hz timer monitors freshness, gaps, and stability
- **Auto-Recovery**: After startup grace, may run `sudo systemctl restart argo_bno085.service` if `/imu` stays absent (~15 s, throttled)

### Monitoring Health
```bash
# Check current health status
ros2 topic echo /imu_health --once

# Monitor health continuously
ros2 topic echo /imu_health

# Via status command
bno085.py status
```

### Failure Scenarios
1. **C++ Driver Crashes**: Health becomes unhealthy after 3s timeout
2. **I2C Communication Failure**: Driver stops sending data, health timeout
3. **Bridge Node Restart**: Health starts unhealthy, recovers on first data

### Compatibility
- **Drop-in Replacement**: Same topic name and semantics as old `imu.py`
- **Lifecycle Integration**: Used by monitoring systems and lifecycle manager

## Calibration

### Understanding BNO085 Calibration
The BNO085 performs **on-chip sensor fusion** and calibration using three main sensors:

1. **Magnetometer** - Measures magnetic field to determine absolute heading
2. **Accelerometer** - Measures gravity and linear acceleration  
3. **Gyroscope** - Measures angular velocity (rotation rate)

### Calibration Accuracy Levels
- **UNRELIABLE (0)** - No calibration data available
- **LOW (1)** - Minimal calibration, may be inaccurate
- **MEDIUM (2)** - Partial calibration, reasonable accuracy
- **HIGH (3)** - Fully calibrated, optimal accuracy

**Target:** Achieve **HIGH (3)** accuracy for all sensors.

### Calibration Process

#### 1. Magnetometer Calibration (Most Important)
**Figure-8 Motion Pattern:**
1. Hold the sensor (or sailboat if mounted)
2. Move in figure-8 pattern through 3D space
3. Rotate through all three axes:
   - Roll: Tilt left and right
   - Pitch: Tilt forward and backward
   - Yaw: Rotate clockwise and counterclockwise

**Requirements:**
- Move slowly and smoothly
- Cover as many different orientations as possible
- Spend at least 30 seconds on each axis
- Avoid metal objects and magnetic interference

#### 2. Accelerometer Calibration (Automatic)
- Auto-calibrates during normal operation
- Experiencing different orientations helps (6-point static calibration)
- Not strictly required - figure-8 motion usually provides adequate calibration

#### 3. Gyroscope Calibration (Automatic)
- Auto-calibrates by analyzing zero-rate offset during stationary periods
- Keep sensor still for 5-10 seconds periodically
- Usually achieves HIGH accuracy quickly (within 30 seconds)

### Using the Calibration Tool
```bash
# Standard 2-minute calibration
bno085.py calibrate

# Custom duration (5 minutes)
bno085.py calibrate --duration 300

# Quick recalibration (1 minute)
bno085.py calibrate --duration 60
```

**Real-Time Display:**
The tool provides live status with progress bars and guidance:
- Shows calibration status for each sensor
- Provides motion guidance ("Motion detected" vs "Move sensor")
- Displays data collection statistics
- Auto-save reminders every 30 seconds

**Success Criteria:**
- **Minimum:** Magnetometer HIGH, others MEDIUM or higher
- **Optimal:** All sensors HIGH accuracy
- **Duration:** 120+ seconds for full calibration

## Integration with Argo

### Lifecycle Manager
The lifecycle manager automatically discovers `bno085.py` and launches it in bridge mode.

### Topic Compatibility
The bridge feeds the same topic names the rest of Argo expects (see [Bridge published topics (Argo)](#bridge-published-topics-argo)):
- `/compass` — compass heading (degrees, CW from north) for control, wind, and plots
- `/pose` — ENU math yaw on `z` for `argo_transform_publisher`, simulator-aligned consumers, and any node that already treated `/pose` as mathematical yaw
- `/accel` — gravity-scaled acceleration (approx. g) for roll/pitch-style consumers
- `/gyro` — angular rates in deg/s
- `/imu_health` — lifecycle and operator health

### Makefile Integration
The `nodes/Makefile` provides convenient shortcuts and automatically uses the configuration file:

```bash
# Build the driver
make bno08x-build

# Quick I2C address scan (not a full SHTP test)
make bno08x-i2c-test

# Full hardware bench test (recommended)
python3 ~/argo/tests/test_bno085.py --skip-ros

# Launch full system (uses bno085_i2c_argo.yaml)
make bno08x-launch-full

# Run calibration
make bno08x-calibrate
```

**Makefile Configuration:**
- **`BNO08X_CONFIG`**: Points to `vendor/bno085_i2c_argo.yaml`
- **Launch targets**: Automatically load the configuration file
- **Build targets**: Use the configuration for driver setup

### Boot ordering on shared I2C bus 0

The IMU shares **i2c-0** with `argo_battery_water.service` (ADC 0x34, SHT45 0x44). BNO085 SHTP init is sensitive to concurrent bus traffic.

- `argo_bno085.service` starts **before** battery/water (`Before=argo_battery_water.service`)
- Battery/water **ExecStartPre** waits until `bno08x_driver` has been stable for 3 s (`scripts/wait_for_bno085_ready.sh`)

See **[README-i2c.md](README-i2c.md)** for bus map, lock recovery, and service install targets (`make -C nodes battery-water-install`, `make -C nodes bno085-service-install`).

## SHTP and SH-2 protocol handling

The BNO085 does **not** use SMBus register reads. It speaks **SHTP** (Sensor Hub Transport Protocol) on plain I2C `read()`/`write()` via `/dev/i2c-0`.

### Protocol layers

```
┌─────────────────────────────────────────────────────────┐
│  ROS2 bno08x_driver  →  sh2.c / shtp.c (vendor C++)     │  SH-2 commands, adverts, sensor reports
├─────────────────────────────────────────────────────────┤
│  I2CInterface::read/write  (i2c_interface.hpp)          │  SHTP framing, 32-byte chunks
├─────────────────────────────────────────────────────────┤
│  Linux i2c-dev  (/dev/i2c-0, address 0x4A)              │  Raw bus access
└─────────────────────────────────────────────────────────┘
```

**SHTP packet layout** (each logical transfer):

| Bytes | Field |
|---|---|
| 0–1 | Length (LSB, MSB with continuation bit in bit 15) |
| 2 | Channel (0=command, 1=executable, 2=SH-2 control, 3=reports, …) |
| 3 | Sequence |
| 4+ | Payload (SH-2 commands/responses or sensor reports) |

**I2C read algorithm** (Argo fork, `i2c_interface.hpp::read()`):

1. Read 4-byte header (length only; idle FIFO returns `[0,0,0,0]` → no data).
2. Read **`packet_size`** bytes into the HAL buffer in ≤32-byte chunks; continuation reads pull **+4** extra wire bytes per chunk and discard the first 4 (Hillcrest SHTP rule).
3. Pass the full buffer to `shtp.c` `rxAssemble()` for multi-fragment assembly.

**SH-2 bring-up** (`sh2_open()`): after soft reset `[5,0,1,0,1]` and 1 s wait, the stack polls reads until executable reset-complete and sensor-hub **advertisements** arrive (Argo fork waits for adverts before treating channel numbers as valid). Failure here surfaces as `SH2_ERR_TIMEOUT` in the journal.

### Argo fork vs stock upstream driver

Submodule path: `nodes/vendor/bno08x_driver/`  
**Upstream reference**: [bnbhat/bno08x-ros2-driver](https://github.com/bnbhat/bno08x-ros2-driver)  
**Argo fork** (pushed to `tobidelbruck/bno08x_ros2_driver`): Orange Pi / shared-bus fixes not in upstream.

| Area | Stock upstream (typical) | Argo fork |
|---|---|---|
| I2C bus default | Often `/dev/i2c-7` in C++ | Patched to `/dev/i2c-0`; **authoritative** bus in `nodes/vendor/bno085_i2c_argo.yaml` |
| `I2CInterface::read()` | Header peek + `memcpy` to buffer + read `packet_size − 4` cargo | **Peek header for length only**, then read **`packet_size`** bytes into buffer (required on Orange Pi `i2c-dev`; upstream-style read desynchronizes the FIFO → `SH2_ERR_TIMEOUT`) |
| Partial reads | Single `read()`; fail on short count | **`readExact_()`** retries `EAGAIN`/`EINTR` (matches bench test behavior) |
| Idle FIFO | May log invalid length | **`packet_size == 0` returns silently** (poll loop during `sh2_open`) |
| Soft reset | 5-byte reset packet | Same packet + **1 s** post-reset delay; **5** write retries |
| `sh2_open()` | Earlier races on adverts | **Wait for reset + sensor-hub adverts** before control traffic |
| I2C errors | Verbose per-read logs | Quiet by default; one-line summary on SH-2 failure (`BNO08X_I2C_VERBOSE=1` for traces) |
| Driver params | Packaged `config/bno085_i2c.yaml` | **Removed from submodule**; Argo uses `nodes/vendor/bno085_i2c_argo.yaml` only |
| Watchdog | Default 5 s | Configurable via yaml (`watchdog.timeout_ms`) |

After changing the submodule, rebuild: `make -C nodes bno08x-build`, then `make -C nodes bno085-service-restart`.

### Standalone hardware test (no ROS)

**`tests/test_bno085.py`** exercises the **same I2C/SHTP path** as the C++ driver but does **not** import or run `bno08x_driver`. It reimplements the HAL read and `shtp.c`-style `rxAssemble` in Python (used to debug bus issues when ROS is irrelevant).

**When to use:**

- Bench check after wiring, resolder, or I2C recovery
- Confirm chip responds before debugging systemd/ROS
- Compare against failing `ros2 run bno08x_driver …` (passing test + failing driver → rebuild driver submodule)

**Stop other i2c-0 users first:**

```bash
sudo systemctl stop argo_bno085.service argo_battery_water.service
```

**Commands** (from repo root):

```bash
# Full hardware path: soft reset, SHTP drain, Product ID vote
python3 tests/test_bno085.py --skip-ros

# Verbose HAL read / rxAssemble traces
python3 tests/test_bno085.py --skip-ros --debug

# Lock part number to Argo BOM (optional)
python3 tests/test_bno085.py --skip-ros --expect-part 0x0098A6B4

# Live accel reports only (skip flaky Product ID path)
python3 tests/test_bno085.py --skip-ros --skip-product-id

# Also require /imu streaming when ROS stack is up
python3 tests/test_bno085.py
```

**Pass criteria:** soft reset + first SHTP packet + Product ID (or accelerometer reports with `--skip-product-id`); optionally non-zero `/imu` rate without `--skip-ros`.

**Note:** `make -C nodes bno08x-i2c-test` only runs `i2cdetect` (address visible). It does **not** validate SHTP; use `test_bno085.py` for that.

**Important:** `smbus2` can leave the fd non-blocking; the test clears `O_NONBLOCK` before `os.read()`, same requirement as reliable blocking reads on this kernel.

## I2C Error Recovery and Reliability

### Automatic Recovery System

The BNO085 bridge includes **automatic I2C error recovery** that monitors sensor health and restarts the systemd service on failures:

#### Health Monitoring
- **Data Timeout**: Detects when no IMU data received for 3+ seconds
- **Failure Tracking**: Counts consecutive failures and total errors per session
- **Recovery Mode**: Switches to 3-second check interval during recovery attempts

#### Recovery Process
1. **Detection**: No IMU data for 3 seconds → sensor marked unhealthy
2. **Service Restart**: Executes `sudo systemctl restart argo_bno085.service`
3. **Throttling**: Recovery attempts limited to every 5 seconds
4. **Logging**: "BNO085 sensor unreachable" logged every 60 seconds during outage
5. **Auto-Recovery**: Returns to normal mode when data resumes

#### Recovery Logs
```bash
# Monitor recovery attempts
journalctl -u argo_bno085.service -f | grep -E "(recovery|unreachable|restart)"

# Example output:
# [ERROR] BNO085 sensor unreachable for 5.0s (recovery attempts: 1, failures: 0)
# [INFO] Attempting recovery #1: Restarting bno08x_driver...
# [INFO] bno08x_driver restart successful
# [INFO] BNO085 sensor recovered - switching to normal mode
```

### Systemd Service Configuration

The `argo_bno085.service` provides robust process management:

**Service File**: `/etc/systemd/system/argo_bno085.service`

```ini
[Unit]
Description=Argo BNO085 IMU Driver Service
After=network.target
Before=argo_battery_water.service argo_launch_standard.service

[Service]
ExecStartPre=/bin/mkdir -p /var/log.hdd/persistent
ExecStart=/home/orangepi/argo/nodes/bno085_driver_launcher.sh
WorkingDirectory=/home/orangepi/argo/nodes
StandardOutput=append:/var/log.hdd/persistent/argo-bno085.log
StandardError=append:/var/log.hdd/persistent/argo-bno085.log
Restart=always
RestartSec=5
User=orangepi
```

**Key Features:**
- **Auto-Restart**: Restarts driver + bridge on failure (5-second delay)
- **Launcher script**: Starts C++ driver, then Python bridge; exits non-zero if either child dies (systemd restarts whole unit)
- **Persistent log**: `/var/log.hdd/persistent/argo-bno085.log` (no `tee` pipeline — allows clean SIGTERM on stop)
- **Journal**: Use `journalctl -u argo_bno085.service` for systemd metadata

### Why Systemd Service is Required

Unlike other Argo sensor nodes, the BNO085 **requires** systemd service management because:

1. **Two-Process Architecture**: Must coordinate C++ driver + Python bridge startup
2. **I2C Recovery**: Python bridge needs sudo privileges to restart the service
3. **Process Lifecycle**: Ensures both processes start/stop together
4. **Auto-Restart**: Recovers from I2C bus errors and driver crashes
5. **Production Reliability**: Systemd provides robust process supervision

### Comparison: Direct I2C vs Service-Managed

| Feature | `anem.py` (Direct I2C) | `bno085.py` (Service-Managed) |
|---|---|---|
| I2C Access | Direct via smbus2 | Via C++ driver |
| Process Count | 1 (Python only) | 2 (C++ + Python) |
| Systemd Service | Optional | **Required** |
| I2C Recovery | Reconnect in-process | Restart entire service |
| Sudo Required | No | Yes (for service restart) |
| Complexity | Low | Medium |
| Reliability | Good | Excellent (systemd supervision) |

## Debugging

### Enabling Driver Debug Output

The BNO08x C++ driver includes comprehensive debug logging that can be enabled for troubleshooting I2C communication and sensor data issues.
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

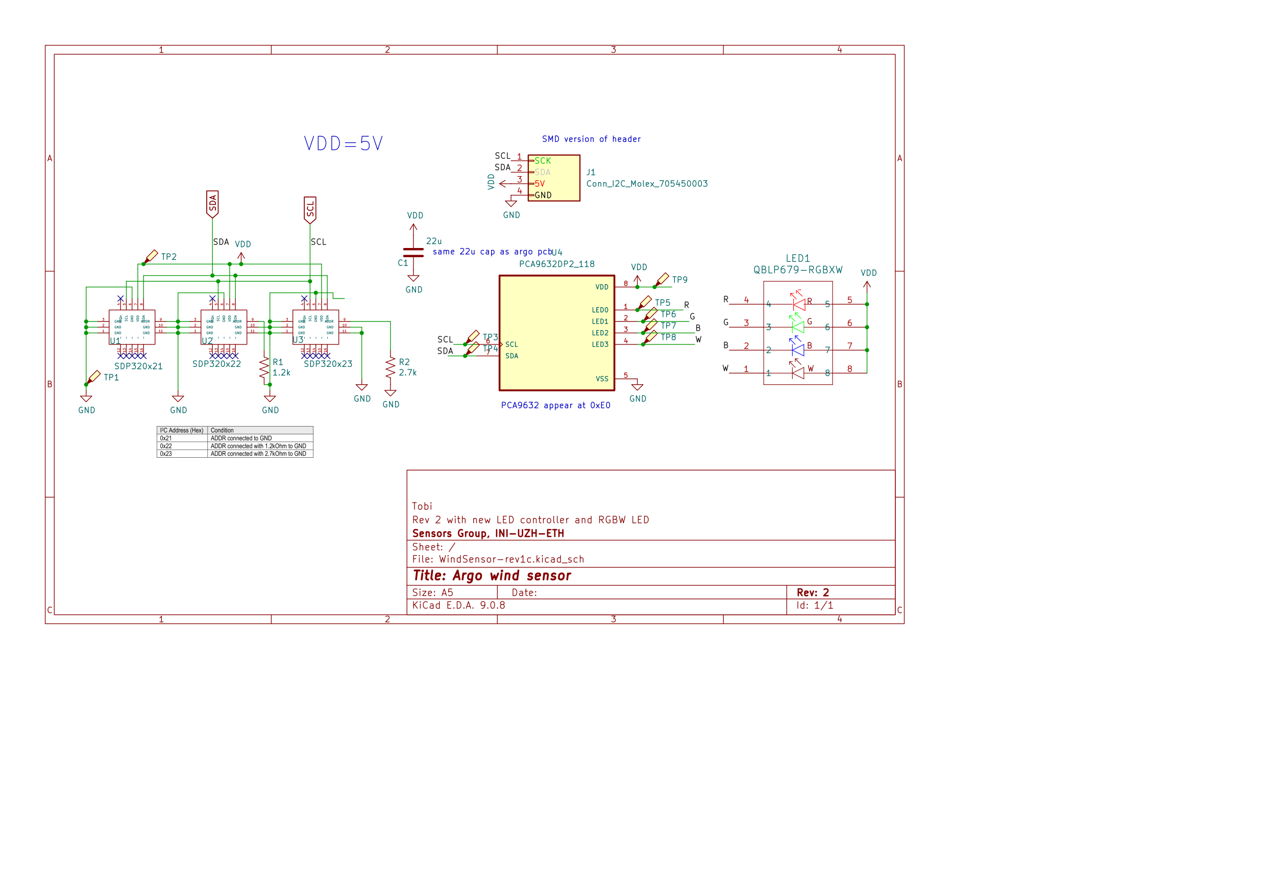
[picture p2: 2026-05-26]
pcb/WindSensor/WindSensor-rev1c/images/WindSensor-rev1c-schematic.png

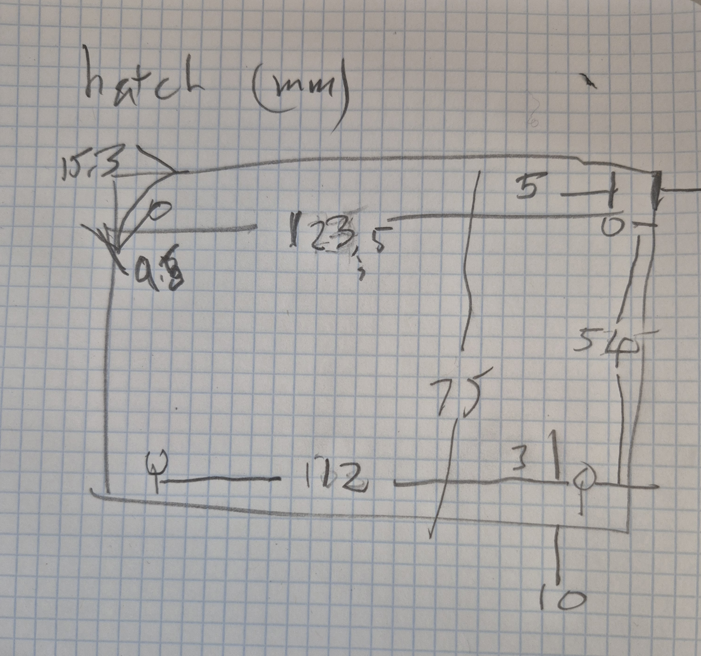
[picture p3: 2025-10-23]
mechanical-3d/argo-hatch-cover/hatch-sketch.jpg

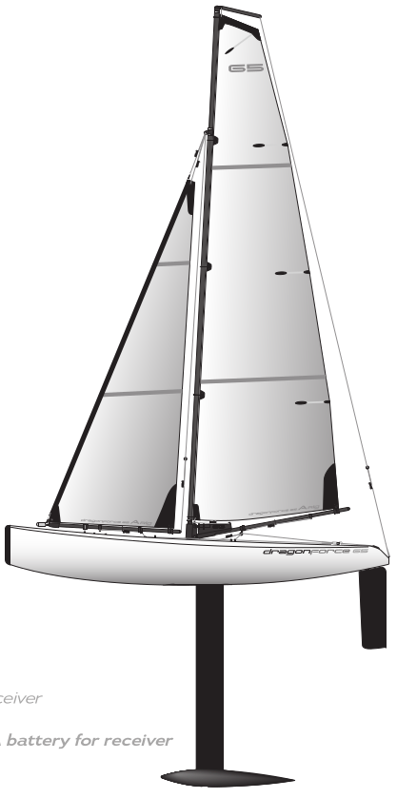
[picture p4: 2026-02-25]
mechanical-3d/df65 side complete bg transparent.png

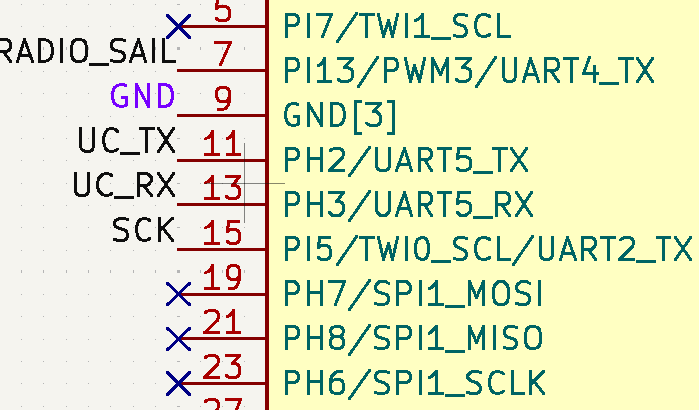
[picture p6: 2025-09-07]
pcb/images/argo gps serial.png

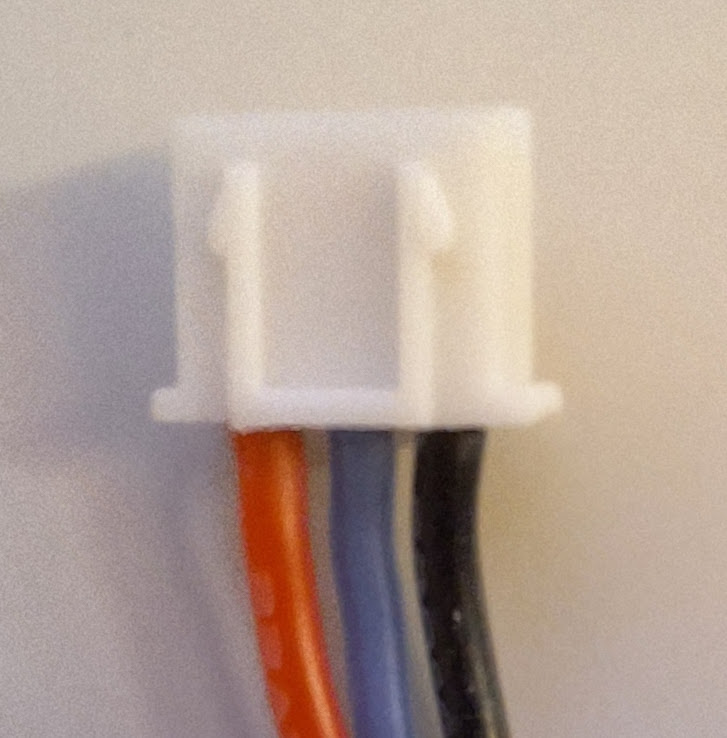
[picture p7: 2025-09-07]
pcb/images/JST_XH2_balance_cable_polarity.jpg

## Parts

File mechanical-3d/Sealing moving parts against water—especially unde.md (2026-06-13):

Sealing moving parts against water—especially under low-tension or small-scale conditions—requires balancing the water tightness of the seal against the **friction** it introduces. Because you are working with small diameters (1.3mm and 0.5mm) and limited tension, traditional high-pressure industrial seals will cause too much binding.

Given your access to **PETG** (for rigid structures) and **TPU** (for flexible seals), here are the best methods to handle both of your specific scenarios.

---

## 1. Sealing the 1.3mm Sliding Rod

A sliding rod (axial movement) is best sealed using a **bellows** or a **tight-tolerance elastomeric pass-through**. Since a 1.3mm rod has very little surface area, a mechanical lip seal might bind it completely.

### Method A: The TPU Sealing Bellows (Highly Recommended)

Instead of sealing *against* the moving rod, you seal the rod permanently to a flexible boot. The boot flexes as the rod moves back and forth, resulting in **zero sliding friction** and a 100% waterproof seal.

* **How it works:** You 3D print a thin-walled, accordion-style bellows out of TPU. One end is tightly clamped or glued to the 1.3mm rod, and the other end is clamped to a rigid PETG through-hull fitting (printed to fit your 6mm opening).
* **Pros:** Absolutely watertight; zero friction on the rod.
* **Cons:** Limits the total travel distance to the expansion/contraction limit of the TPU bellows.

### Method B: Lubricated Pushrod Guide Tube

Commonly used in RC marine applications, this relies on a close-tolerance tube packed with viscous, water-insoluble grease.

* **How it works:** Print a PETG sleeve that slips into your 6mm hull opening. The inside diameter (ID) of this sleeve should be just slightly larger than the rod (e.g., 1.5mm to 1.6mm). Pack the inside of this tube with **marine grease** or **silicone grease**.
* **Pros:** Very low friction; simple to implement; unlimited travel distance.
* **Cons:** The grease will slowly migrate out over time and requires periodic reapplication.

---

## 2. Sealing the 0.5mm Dyneema Winch Line

Sealing a braided or monofilament line is notoriously difficult because water can wick through the braid, and the line lacks the rigidity to push past a tight rubber seal without bunching up—especially with an elastic return cord.

### Method A: The High-Tube / Snorkel System (Highly Recommended)

If the winch line is exiting the hull *above* the waterline (or if the hull only experiences brief splashes/heeling rather than total submersion), the best seal is a **gravity-based snorkel tube**.

* **How it works:** Print a rigid PETG tube that mounts into your 6mm hull opening. Route this tube internally so that it extends **well above the external waterline** of the vessel before the line exits the tube into the hull interior.
* **Pros:** **Zero friction** on your 0.5mm line, allowing the elastic cord to work perfectly. 100% reliable as long as the top of the tube remains higher than the water level outside.
* **Cons:** Does not protect against complete submersion or capsizing.

### Method B: TPU Squeegee / Grommet with Marine Grease

If the opening *must* be submerged, you need a physical barrier, but it must be incredibly compliant.

* **How it works:** Print a PETG plug for the 6mm hole with a hollow internal chamber. Caps on either side of the chamber should have a tiny 0.6mm hole. Print a thin TPU diaphragm (0.4mm to 0.8mm thick) with a tiny pinhole (approx. 0.3mm) for the line to pass through. Fill the internal PETG chamber with heavy silicone grease.
* **Pros:** Works dynamically under water.
* **Cons:** Dyneema is inherently slippery but textured; it will drag tiny amounts of water past the seal via capillary action, and the friction might require you to beef up your elastic return cord.

---

## Practical 3D Printing & Design Tips

* **Perimeter Settings for PETG:** When printing your through-hull fittings or tubes from PETG, increase your perimeter/wall count so that the part is entirely solid walls rather than infill. Print slightly hot to ensure maximum layer adhesion, preventing water from weeping *through* the 3D printed layers themselves.
* **TPU Thickness:** To keep friction low on a 0.5mm line or a 1.3mm rod, your TPU seals need to be incredibly thin. Design them to be only **1 to 2 perimeters thick** (using a 0.4mm nozzle) so they remain highly flexible.
* **Coating the Line:** To prevent the Dyneema line from acting like a wick, rub it thoroughly with beeswax or silicone grease before threading it through the seal. This fills the microscopic voids in the braid.

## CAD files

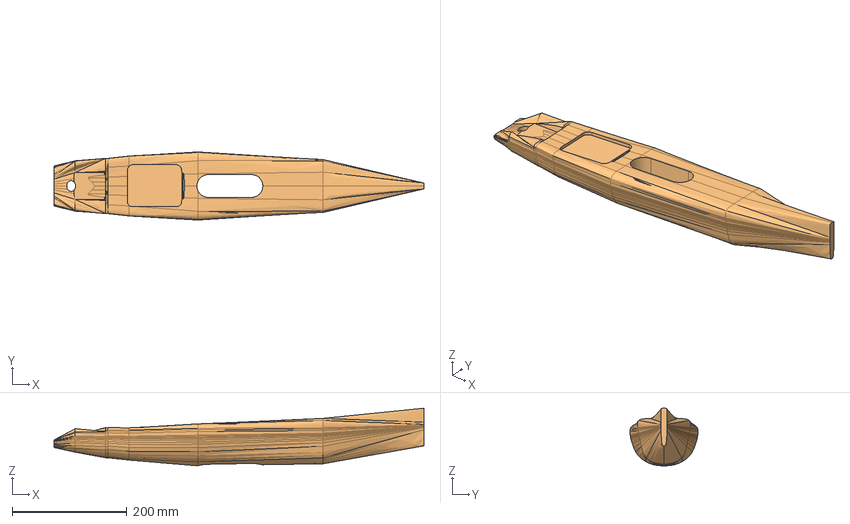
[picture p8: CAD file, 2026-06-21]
mechanical-3d/argo-pcb-in-def65-hull-1.1.FCStd
645.0 x 118.8 x 100.4 mm
R_0603_1608Metric
OPiZ2W_
R_0603_1608Metric001
R_0603_1608Metric002
C_0603_1608Metric
D_0603_1608Metric
SSOP-8_2.95x2.8mm_P0.65mm
gps_module
ant_cable
R_0603_1608Metric003
R_0603_1608Metric004
R_0603_1608Metric005
PinHeader_1x03_P2.54mm_Vertical
R_0603_1608Metric006
R_0603_1608Metric007
C_1210_3225Metric
R_0603_1608Metric008
R_0603_1608Metric009
C_0603_1608Metric001
R_0603_1608Metric010
R_0603_1608Metric011
LED_0603_1608Metric
R_0603_1608Metric012
R_0603_1608Metric013
SW_Tactile_SPST_NO_Straight_CK_PTS636Sx25SMTRLFS
C_0603_1608Metric002
SW_Tactile_SPST_NO_Straight_CK_PTS636Sx25SMTRLFS001
USB_C_Receptacle_GCT_USB4125-xx-x-0190_6P_TopMnt_Horizontal
R_0603_1608Metric014
R_0603_1608Metric015
LED_0603_1608Metric001
LED_0603_1608Metric002
C_0603_1608Metric003
R_0603_1608Metric016
LED_0603_1608Metric003
JST_XH_S2B-XH-A_1x02_P2.50mm_Horizontal
C_1210_3225Metric001
R_0603_1608Metric017
R_0603_1608Metric018
R_0603_1608Metric019
CMI-9653S-SMT
R_0603_1608Metric020
LED_0603_1608Metric004
PinHeader_1x03_P2.54mm_Vertical001
MSOP-8_3x3mm_P0.65mm
C_0603_1608Metric004
PinHeader_1x03_P2.54mm_Vertical002
R_0603_1608Metric021
R_0603_1608Metric022
C_0603_1608Metric005
LED_0603_1608Metric005
U2-P_NCH
C_0603_1608Metric006
R_0603_1608Metric023
SSOP-8_2.95x2.8mm_P0.65mm001
antenna
shaft
Daughterboard_3D_Model
LED_0603_1608Metric006
C_1210_3225Metric002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

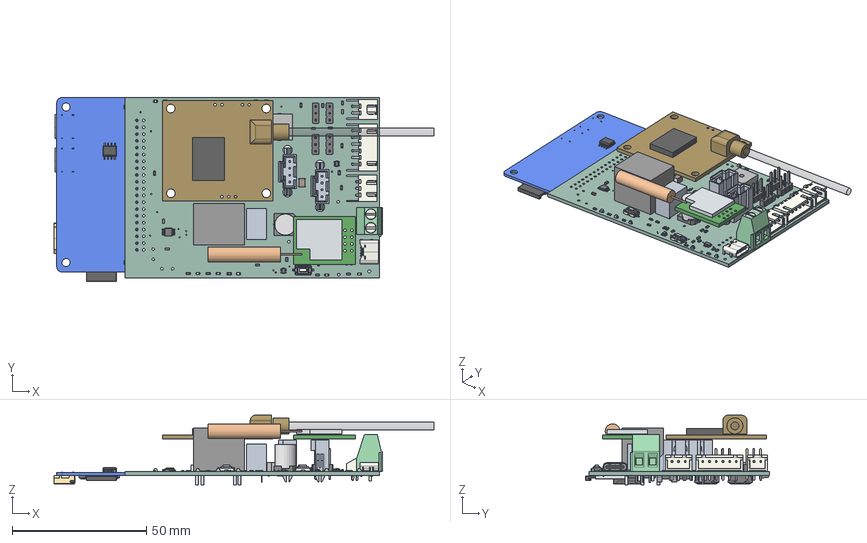
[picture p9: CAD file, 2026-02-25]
pcb/argo-v9-stable/argo-v9-stable-rev4/argo-v9-stable-rev4.step
141.6 x 68.6 x 26.0 mm
R_0603_1608Metric x 41
OPiZ2W_
C_0603_1608Metric x 8
D_0603_1608Metric
SSOP-8_2.95x2.8mm_P0.65mm x 2
gps_module
ant_cable
PinHeader_1x03_P2.54mm_Vertical x 4
C_1210_3225Metric x 5
LED_0603_1608Metric x 7
SW_Tactile_SPST_NO_Straight_CK_PTS636Sx25SMTRLFS x 2
USB_C_Receptacle_GCT_USB4125-xx-x-0190_6P_TopMnt_Horizontal
JST_XH_S2B-XH-A_1x02_P2.50mm_Horizontal
CMI-9653S-SMT
MSOP-8_3x3mm_P0.65mm
U2-P_NCH
antenna
shaft
Daughterboard_3D_Model
JST_XH_S3B-XH-A-1_1x03_P2.50mm_Horizontal
TS4148_RCG x 2
TSOT-23-6
TerminalBlock_Phoenix_MKDS-1,5-2-5.08_1x02_P5.08mm_Horizontal
SOT-363_SC-70-6 x 2
JST_XH_S6B-XH-A_1x06_P2.50mm_Horizontal
Leads
argo-v9-stable-rev4_PCB

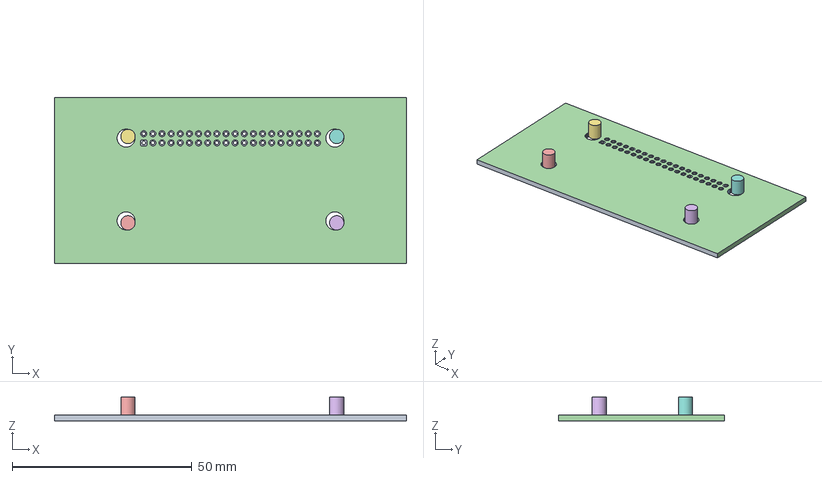
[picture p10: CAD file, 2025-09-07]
pcb/orange-pi/orange pi zero 2w 3d.FCStd
97.8 x 46.1 x 6.60 mm
topPads
btmPads
TH-Drills
PCB
PCB001

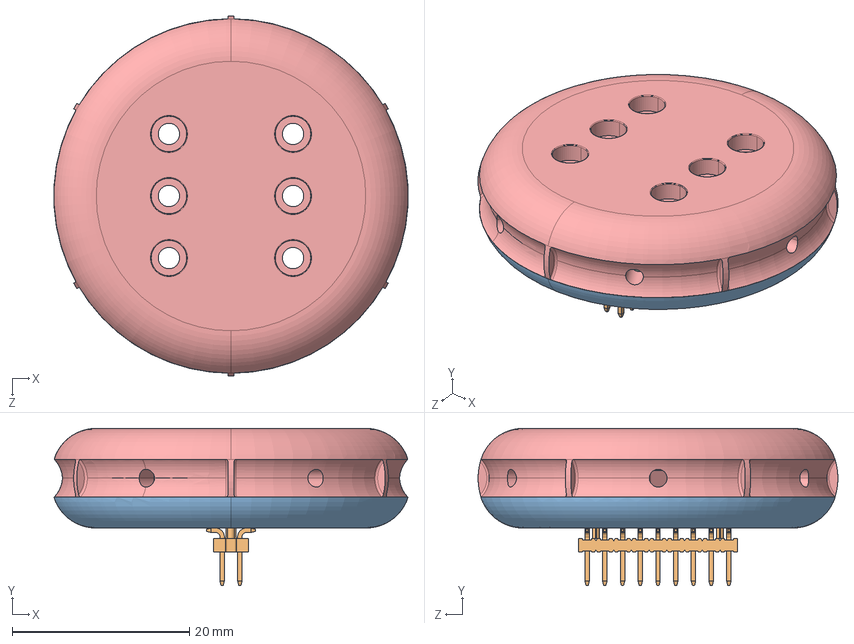
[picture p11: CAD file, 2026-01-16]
pcb/WindSensor/DP_CAD_SDP3x_DirectionalWindmeter_D2.step
39.9 x 17.8 x 40.6 mm
Xanadu_Pitot_PCB_00
Xanadu_Pitot_Schale_1_00
Xanadu_Pitot_Dichtung_00
Xanadu_Pitot_Schale_2_2mm_Wandungen_00

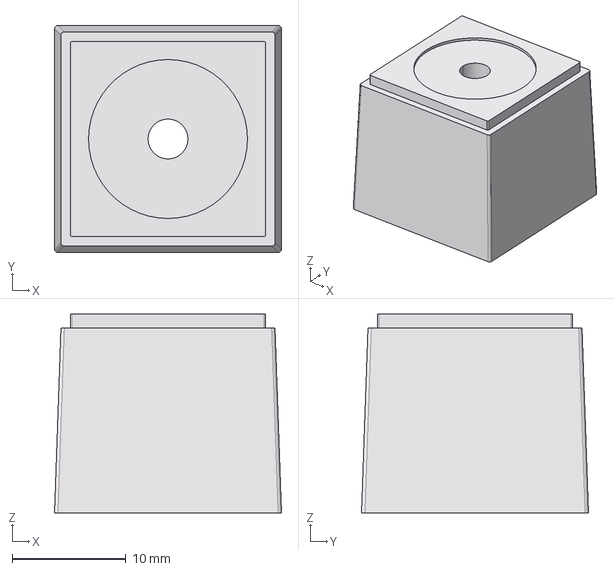
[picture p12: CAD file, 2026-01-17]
pcb/WindSensor/I2C cable gland/Weidmuller CABTITE SE 3-4 SML GY 2583400000.stp
20.0 x 20.0 x 17.5 mm

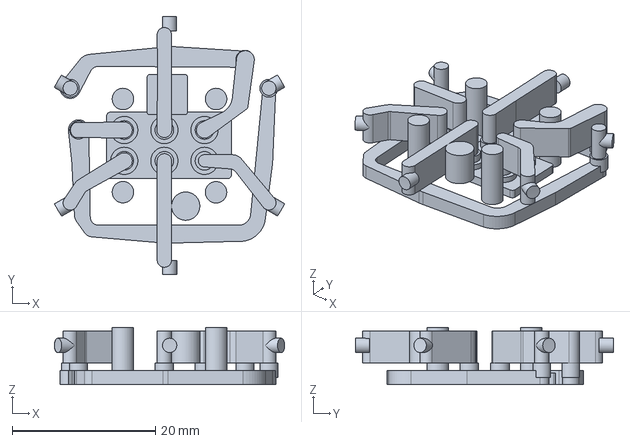
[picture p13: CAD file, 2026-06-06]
pcb/WindSensor/WindSensor-rev1c/WindSensor3D-rev1c.FCStd
32.1 x 36.0 x 8.00 mm

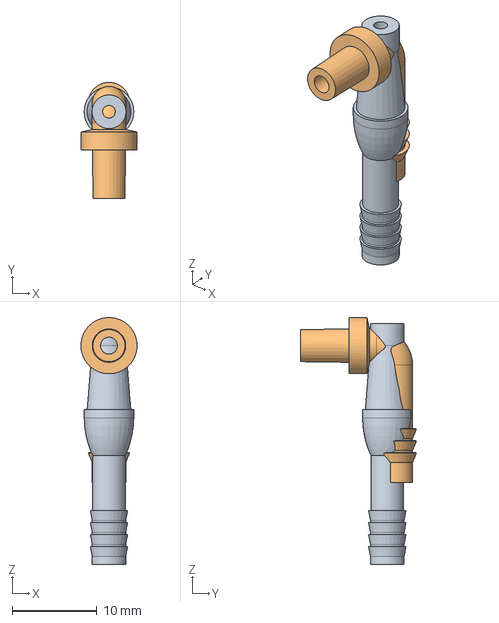
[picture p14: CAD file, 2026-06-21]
mechanical-3d/Rudder Winch glands.FCStd
6.65 x 13.7 x 29.2 mm
pressure coupler
pressure coupler_RA

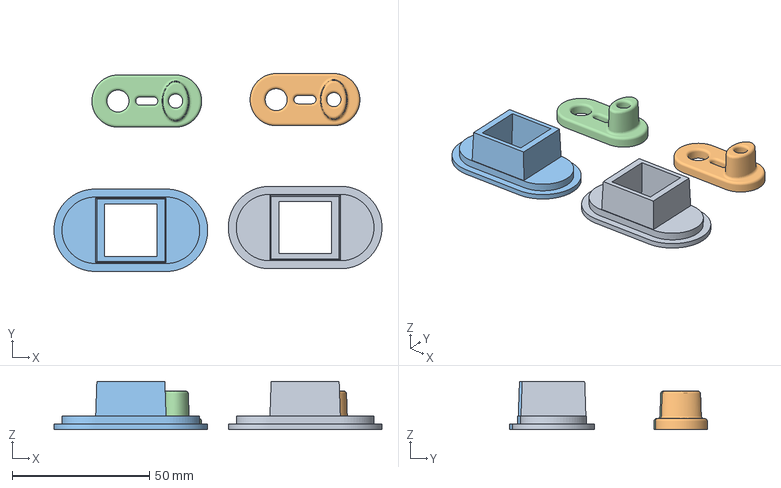
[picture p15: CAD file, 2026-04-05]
pcb/WindSensor/WindSensor-rev1c/WindSensor3D-rev1c-ArgoWindSensor-both.3mf
119.5 x 72.1 x 17.5 mm
WindSensor3D-rev1c-windsensor-cable-glandcable-gland-housing x 2
WindSensor3D-rev1c-mast step up x 2

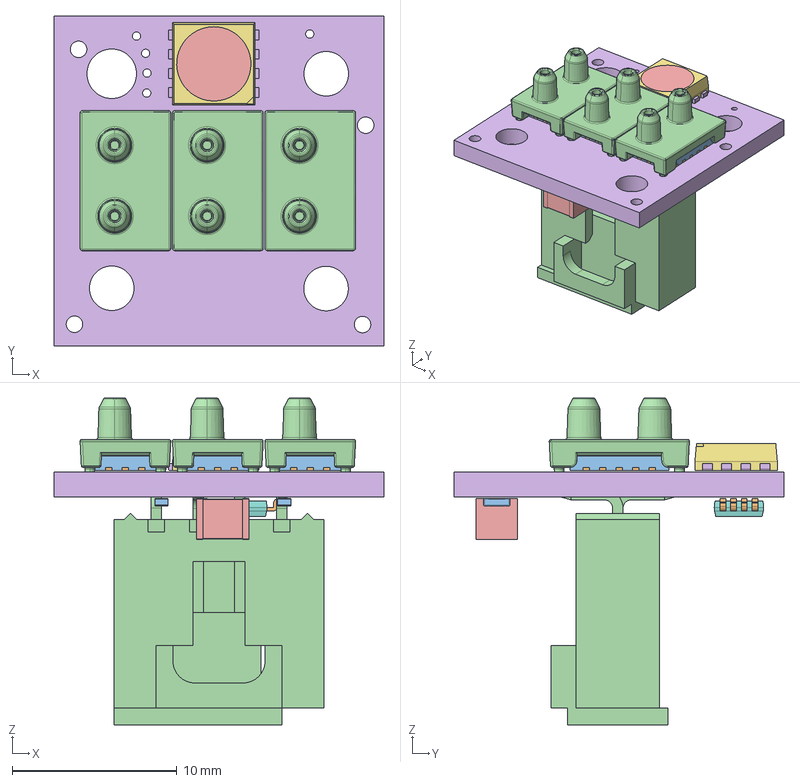
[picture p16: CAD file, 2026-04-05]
pcb/WindSensor/WindSensor-rev1c/WindSensor-rev1c.step
20.0 x 20.0 x 19.8 mm
Sensirion_Differential_Pressure_Sensors_SDP3x_STEP_file x 3
PCA9632DP1_118
R_0603_1608Metric x 2
C_1210_3225Metric
WindSensor-rev1c_PCB

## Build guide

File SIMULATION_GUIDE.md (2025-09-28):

# Argo Simulation Guide

This guide explains how to run Argo in simulation mode, both locally and remotely, avoiding conflicts with hardware nodes.

## Overview

When running simulation, several hardware nodes conflict with the simulator topics:

**Conflicting Hardware Nodes (excluded in simulation):**
- `gps.py` → publishes `/gps_cog`, `/gps_sog`, `/gps_velocity` (conflicts with simulator)
- `imu.py` → publishes `/compass` (conflicts with simulator) 
- `anem.py` → publishes `/anem_speed_angle_temp` (conflicts with simulator)
- `rudder_sail_radio.py` → subscribes to `/rudder_sail_servo` (conflicts with simulator control)

**Nodes that run in simulation:**
- `argo_unified_simulator_bridge.py` → provides simulated sensor data
- `controller.py` → autonomous navigation
- `battery_water.py` → hardware monitoring (no conflicts)
- `temp_monitor.py` → hardware monitoring (no conflicts)

## Simulation Modes

### 1. Local Simulation

Runs the simulator directly on the Orange Pi.

**Features:**
- Uses sailboat-playground or mock simulator
- Provides simulated sensor data
- Handles control commands locally
- No network dependencies

**Usage:**

```bash
# Method 1: Using lifecycle manager
python3 launch/argo_lifecycle_manager.py simulate

# Method 2: Using launch script
./scripts/launch_simulator_local.sh

# Method 3: Manual launch
python3 nodes/argo_unified_simulator_bridge.py --mode local &
python3 nodes/controller.py --ros-args --params-file nodes/argo.yaml &
python3 nodes/battery_water.py &
python3 nodes/temp_monitor.py &
```

### 2. Remote Simulation

Connects to a remote simulator running on another machine.

**Features:**
- Offloads CPU-intensive simulation to remote machine
- Forwards sensor data from remote simulator
- Sends control commands to remote simulator
- Monitors connection status

**Prerequisites:**
1. Remote machine with Argo project cloned
2. SSH access to remote machine
3. ROS2 Humble installed on remote machine

**Setup:**

```bash
# 1. Setup remote machine (one-time)
./scripts/setup_remote_simulator.sh

# 2. Start SSH tunnel (terminal 1)
./scripts/remote_simulator_tunnel.sh

# 3. Start remote simulator (terminal 2)
python3 scripts/remote_simulator_launch.py

# 4. Start local simulation (terminal 3)
./scripts/launch_simulator_remote.sh
```

## Unified Simulator Bridge

The `argo_unified_simulator_bridge.py` replaces both `argo_simulator_bridge.py` and `argo_remote_simulator_bridge.py`:

**Local Mode:**
- Runs sailboat-playground or mock simulator
- Publishes simulated sensor data
- Handles control commands locally

**Remote Mode:**
- Connects to remote simulator via ROS2 topics
- Forwards sensor data from remote
- Sends control commands to remote
- Monitors connection health

## Topic Mapping

The simulator bridge provides these topics to the Argo system:

**Published Topics (Simulator → Argo):**
- `/pose` - IMU compass heading (Vector3, z=heading degrees)
- `/compass` - Raw compass data (Vector3, z=heading degrees)
- `/gps_cog` - Course over ground (Float64, degrees)
- `/gps_sog` - Speed over ground (Float64, knots)
- `/gps_velocity` - GPS velocity vector (Vector3, x=north, y=east, z=speed knots)
- `/anem_speed_angle_temp` - Wind data (Vector3, x=speed m/s, y=angle degrees, z=temp °C)
- `/rudder_sail_radio` - Mock human input (Vector3, x=rudder, y=sail, z=0)

**Subscribed Topics (Argo → Simulator):**
- `/rudder_sail_servo` - Control commands from Argo (Vector3, x=rudder, y=sail)
- `/human_controlled` - Control mode status (Bool, true=human, false=robot)

## Configuration

### Centralized Configuration

All remote simulation settings are centralized in `scripts/remote_simulator_config.json`:

```json
{
  "remote": {
    "host": "sensors-tobidh87.lan.ini.uzh.ch",
    "user": "tobi",
    "argo_dir": "/home/tobi/Dropbox/GitHub/SensorsINI/argo"
  },
  "ros2": {
    "domain_id": 42
  },
  "network": {
    "local_port": 11311,
    "remote_port": 11311
  },
  "ssh": {
    "timeout": 10,
    "key_path": "~/.ssh/id_rsa"
  }
}
```

### Loading Configuration

Both Python and shell scripts load configuration using `scripts/load_config.py`:

```bash
# Shell scripts
eval "$(python3 scripts/load_config.py --export-shell)"

# Python scripts
from load_config import load_config
config = load_config()
```

## Troubleshooting

### Local Simulation Issues

1. **sailboat-playground not available:**
   - Check if simulator submodule is initialized: `git submodule update --init`
   - Verify sailboat-playground is in `simulator/` directory

2. **Mock simulator fallback:**
   - This is normal if sailboat-playground fails to load
   - Mock simulator provides basic physics simulation

### Remote Simulation Issues

1. **Connection timeout:**
   - Check SSH tunnel: `./scripts/remote_simulator_tunnel.sh`
   - Verify remote simulator is running
   - Check network connectivity

2. **ROS2 communication issues:**
   - Ensure both machines use same ROS_DOMAIN_ID
   - Check firewall settings
   - Verify SSH tunnel is active

3. **Remote setup issues:**
   - Run setup script: `./scripts/setup_remote_simulator.sh`
   - Check ROS2 installation on remote machine
   - Verify Python dependencies

### Debug Commands

```bash
# Check node status
python3 launch/argo_lifecycle_manager.py status

# Monitor system
python3 launch/argo_lifecycle_manager.py monitor

# Debug remote connection
./scripts/debug_remote_ros2.sh

# Test simulator bridge
python3 nodes/argo_unified_simulator_bridge.py --mode local --help
```

## Benefits

### Local Simulation
- No network dependencies
- Fast startup
- Good for development and testing
- Uses local CPU resources

### Remote Simulation
- Offloads CPU-intensive simulation
- Better performance on resource-constrained Orange Pi
- Scalable (multiple simulators on different machines)
- Isolation (simulator crashes don't affect local system)

## Migration from Old Bridges

The unified simulator bridge replaces the old separate bridges:

**Old approach:**
- `argo_simulator_bridge.py` (local only)
- `argo_remote_simulator_bridge.py` (remote only)

**New approach:**
- `argo_unified_simulator_bridge.py` (both local and remote)

**Migration:**
1. Use `--mode local` instead of `argo_simulator_bridge.py`
2. Use `--mode remote` instead of `argo_remote_simulator_bridge.py`
3. Update launch scripts to use unified bridge
4. Remove old bridge files (optional)

This unified approach reduces code duplication and provides a consistent interface for both simulation modes.

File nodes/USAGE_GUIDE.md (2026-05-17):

# Argo Two-Node Control System Usage Guide

This guide shows how to use the new two-node control system that separates high-level autonomous control from low-level hardware control and human/robot arbitration.

## Quick Start

### 1. Launch the System
```bash
# Terminal 1: Low-level control and arbitration
cd ~/argo
python3 nodes/rudder_sail_radio.py --ros-args --params-file nodes/argo.yaml

# Terminal 2: High-level autonomous control
cd ~/argo  
python3 nodes/controller.py --ros-args --params-file nodes/argo.yaml

# Terminal 3: Monitor system status (optional)
cd ~/argo
ros2 topic echo /human_controlled
```

### 2. Monitor System Status
```bash
# Watch control authority (who has control)
ros2 topic echo /human_controlled

# Watch autonomous commands
ros2 topic echo /rudder_sail_cmd

# Watch final hardware commands  
ros2 topic echo /rudder_sail_servo

# Watch detailed control status
ros2 topic echo /control_authority
```

## Key Features

### 🚨 Human Priority Control
- **Any radio input immediately grants human control**
- No button presses or mode switches required
- Move rudder or sail stick > 0.05 units and you have control
- Robot waits for 2 seconds of inactivity before taking back control

### 🛡️ Safety Features
- All commands clamped to safe limits (±1.0 by default)
- Human override works even if autonomous system fails
- 20Hz control loop for responsive arbitration
- Separate nodes mean hardware control continues if high-level control fails

### 🔄 Seamless Transitions
- Target heading automatically updated during human control
- Smooth handover between human and robot control
- No jerky transitions or mode switches

## Control Flow Examples

### Scenario 1: Normal Autonomous Operation
```
1. Both nodes start up
2. Human moves radio → Human gets immediate control
3. Human stops moving radio for 2+ seconds
4. Robot takes control with last human heading as target
5. Robot maintains heading using autonomous control
```

### Scenario 2: Human Override
```
1. Robot is controlling boat autonomously
2. Human moves radio stick (any amount > 0.05)
3. IMMEDIATELY: Human has control, robot commands ignored
4. Human controls boat directly
5. Human stops → Robot takes back control after 2 seconds
```

### Scenario 3: Emergency Takeover
```
1. Robot control active
2. Emergency situation detected by human
3. Human grabs radio and moves any control
4. INSTANT human override - no delays, no mode switches
5. Human has full control immediately
```

## Configuration Options

### Basic Configuration (argo.yaml)
```yaml
# High-level controller
controller_node:
  ros__parameters:
    controller_type: "proportional"     # or "wind_aware"
    rudder_gain: 2.0                   # Heading control sensitivity
    rudder_full_scale_deg: 60.0        # Full rudder at 60° heading error

# Low-level arbitration
rudder_sail_radio_node:
  ros__parameters:
    human_override_timeout: 2.0        # Seconds before robot can take control
    deadband_threshold: 0.40           # Minimum radio change to detect human (see argo.yaml)
    safety_max_rudder: 1.0            # Maximum rudder command
    safety_max_sail: 1.0              # Maximum sail command
```

### Conservative Human Priority
```yaml
rudder_sail_radio_node:
  ros__parameters:
    human_override_timeout: 5.0        # Longer timeout (5 seconds)
    deadband_threshold: 0.30           # More sensitive (lower = easier false triggers from RC noise)
    safety_max_rudder: 0.8            # More conservative limits
    safety_max_sail: 0.8
```

### Wind-Aware Autonomous Control
```yaml
controller_node:
  ros__parameters:
    controller_type: "wind_aware"      # Use wind-based sail control
    rudder_gain: 1.5                   # Slightly less aggressive
    sail_wind_gain: 0.3               # 30% wind-based, 70% radio-based sail
```

## Monitoring and Debugging

### Check System Health
```bash
# Are both nodes running?
ros2 node list | grep -E "(controller|rudder_sail_radio)"

# Is sensor data flowing?
ros2 topic hz /pose /compass /anem_speed_angle_temp

# Is radio input working?
ros2 topic echo /rudder_sail_radio

# Are autonomous commands being generated?
ros2 topic echo /rudder_sail_cmd
```

### Debug Control Authority Issues
```bash
# Check detailed control status
ros2 topic echo /control_authority
# x: 1=human control, 0=robot control  
# y: seconds since last human activity
# z: seconds since last autonomous command

# Check for radio input changes
ros2 topic echo /rudder_sail_radio
# Look for changes > 0.05 in x (rudder) or y (sail)
```

### Monitor Control Performance
```bash
# Compare autonomous vs final commands
ros2 topic echo /rudder_sail_cmd     # What controller.py wants
ros2 topic echo /rudder_sail_servo   # What actually goes to hardware

# Should be identical during robot control
# Should be different during human control
```

## Troubleshooting

### Problem: Robot never takes control
```bash
# Check if radio input is constantly changing (noise)
ros2 topic echo /rudder_sail_radio

# Solution: Increase deadband_threshold or check radio calibration
```

### Problem: Human can't override robot
```bash
# Check if radio input is reaching the system
ros2 topic echo /rudder_sail_radio

# Check if changes are above deadband threshold
# Solution: Lower deadband_threshold or fix radio hardware
```

### Problem: Jerky transitions
```bash
# Check human_override_timeout setting
# Solution: Tune timeout value (try 1.0-5.0 seconds)
```

### Problem: Autonomous control not working
```bash
# Check if controller.py is receiving sensor data
ros2 topic echo /pose

# Check if autonomous commands are being generated
ros2 topic echo /rudder_sail_cmd

# Check controller configuration
ros2 param get /controller_node controller_type
```

## Data Collection

### Enable Training Data Collection
```yaml
controller_node:
  ros__parameters:
    data_collection_enabled: true
```

### Collect Training Data
1. Enable data collection in config
2. Restart controller.py
3. Operate boat in human control mode
4. Data automatically saved to `training_data/` directory
5. Use existing analysis tools from control_refactored.py

## Migration from Original Control

### From control.py
- Replace `python3 nodes/control.py` with the two-node system
- Same sensor inputs and control logic
- Enhanced robustness and human priority

### From control_refactored.py  
- All controller types work the same way
- Same data collection features
- Same parameter hot-reloading
- Added robust human override and hardware arbitration

## System Architecture Summary

```
Sensors → controller.py → /rudder_sail_cmd → rudder_sail_radio.py → Hardware
    ↓                                              ↑
    └─ Target heading management              Radio input
                                              Human override
                                              Safety limits
```

The key innovation is the **human priority arbitration** in `rudder_sail_radio.py` that ensures humans can always immediately take control without any mode switches or button presses - just move the radio controls and you have instant authority over the boat.

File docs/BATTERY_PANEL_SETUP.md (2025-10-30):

# Argo Battery Status Panel for XFCE4

This document describes how to add battery status from the Argo sailboat system to the XFCE4 desktop panel.

## Overview

The battery status panel displays real-time battery information from the `argo_battery_water.py` ROS2 node, including:
- Battery voltage and percentage
- Charging status
- AC power presence
- Critical alerts (low battery, saltwater intrusion, high humidity)

## Files Created

- `scripts/battery_status_panel.py` - Main battery status panel with continuous updates
- `scripts/battery_status_simple.py` - Simple one-shot battery status display
- `scripts/battery_status_wrapper.sh` - Wrapper script with ROS2 environment
- `scripts/argo_battery_panel.sh` - Alternative launcher script
- `scripts/setup_battery_panel.sh` - Setup and configuration script
- `.local/share/applications/argo-battery-panel.desktop` - Desktop entry

## Quick Setup

1. Run the setup script:
   ```bash
   cd ~/argo
   ./scripts/setup_battery_panel.sh
   ```

2. Follow the on-screen instructions to add the Generic Monitor plugin to your XFCE4 panel

## Manual Setup

### Option 1: Generic Monitor Plugin (Recommended)

1. Right-click on the XFCE4 panel
2. Select "Panel" → "Add New Items..."
3. Choose "Generic Monitor" and click "Add"
4. Right-click the new Generic Monitor and select "Properties"
5. Configure the plugin:
   - Command: `~/argo/scripts/battery_status_genmon_wrapper.sh`
   - Update interval: 10 seconds (or your preference)
   - Label: Leave empty or set to "Battery"
6. Click "Close" to save

### Option 2: Terminal Command

You can always check battery status manually:
```bash
~/argo/scripts/battery_status_wrapper.sh
```

## Generic Monitor Plugin Features

The Generic Monitor plugin provides rich display capabilities:

- **Dynamic Icons**: Changes based on battery status (charging, low, normal)
- **Color-coded Text**: Green for normal, red for alerts
- **Detailed Tooltips**: Hover to see comprehensive battery information
- **Click Actions**: Click to open detailed status dialog (if zenity is available)
- **Real-time Updates**: Configurable update interval (default: 10 seconds)

## Display Format

The battery status displays with icons and text:

- `🔋 7.2V (45%) 🔌⚡` - Normal battery with charging and AC power
- `🔴 6.8V (15%) 🔋` - Low battery warning
- `💧 7.1V (42%) 🔌` - Saltwater intrusion detected
- `💦 7.3V (48%) ⚡` - High humidity detected
- `🔋 Service unavailable` - Battery service not available
- `🔋 Error` - Service error or timeout

## Icons Legend

- `🔋` - Normal battery
- `🔴` - Low battery alert
- `💧` - Saltwater intrusion
- `💦` - High humidity
- `🔌` - Charging active
- `⚡` - AC power present

## Troubleshooting

### Battery Status Not Appearing

1. Check if argo_battery_water node is running:
   ```bash
   ros2 service list | grep battery_status
   ```

2. Test the display manually:
   ```bash
   ~/argo/scripts/battery_status_wrapper.sh
   ```

3. Check ROS2 environment:
   ```bash
   source /opt/ros/humble/setup.bash
   ros2 service call /battery_status std_srvs/srv/Trigger
   ```

### Service Not Available

If the battery service is not available:
1. Start the argo_battery_water node:
   ```bash
   python3 ~/argo/nodes/argo_battery_water.py
   ```

2. Or start the full Argo system:
   ```bash
   al  # Using Argo CLI alias
   ```

### Error Handling

The battery panel includes robust error handling:
- **Throttled logging**: Errors are logged max once every 30 seconds
- **Graceful degradation**: Shows "Service unavailable" when service is down
- **Automatic recovery**: Resumes normal operation when service returns
- **Timeout handling**: 2-second timeout for service calls

## Configuration

### Update Intervals

- **Panel script**: 5 seconds (configurable with `--update-interval`)
- **Simple script**: One-shot display
- **XFCE4 Generic Monitor**: 10 seconds (recommended)

### Customization

You can modify the display format by editing the `_format_battery_display()` method in the Python scripts.

## Integration with Argo System

The battery panel integrates seamlessly with the Argo sailboat system:
- Uses the existing `/battery_status` service from `argo_battery_water.py`
- Respects the same error handling and logging patterns
- Works with the Argo lifecycle management system
- Compatible with simulation mode (shows mock data)

## Dependencies

- ROS2 Humble
- Python 3
- XFCE4 desktop environment
- `argo_battery_water.py` node running
- `std_srvs` ROS2 package

## Notes

- The panel will show "Service unavailable" when the Argo system is not running
- Battery status updates automatically when the Argo system starts
- No manual intervention required after initial setup
- Works in both real hardware and simulation modes

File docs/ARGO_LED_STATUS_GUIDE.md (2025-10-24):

# Argo LED Status Display Guide

## Quick Reference for Hatch Cover

### LED Slot System (3-second cycle)
- **10 slots** of 0.3 seconds each (0.03s on + 0.27s off)
- **Pattern format**: `g.... .....` (green in slot 1, then off)
- **Color combinations**: 
  - `g` = green, `r` = red, `b` = blue
  - `y` = yellow (red+green), `p` = purple (red+blue), `c` = cyan (green+blue)

### Status Patterns
- **Basic alive**: `g.... .....` (1 green flash)
- **Nodes running**: `gg.... ....` (2 green flashes)
- **Recording active**: `ggg.... ...` (3 green flashes)
- **Single failure**: `gr.... ....` (1 green + 1 red)
- **Multiple failures**: `grr.... ...` (1 green + 2 red)
- **Critical battery**: `b.... .....` (1 blue flash)

### Failure Indicators (Red Flashes)
- **1 red flash**: Anemometer not connected/failed
- **2 red flashes**: + Network/WiFi connection lost
- **3 red flashes**: + GPS fix lost  
- **4 red flashes**: + LoRa shore connection lost

## Complete Status Examples

### Normal Operation
- **Pattern**: `gg.... ....` (2 green flashes for nodes running)

### Recording Active  
- **Pattern**: `ggg.... ...` (3 green flashes for recording)

### Anemometer Failed
- **Pattern**: `ggr.... ...` (2 green + 1 red for anemometer failure)

### Multiple Failures
- **Pattern**: `grrr.... ..` (1 green + 3 red for multiple failures)

### Critical Battery
- **Pattern**: `b.... .....` (1 blue flash for critical battery)

### Complex States
- **Recording + Failures**: `gggr.... ..` (3 green + 2 red)
- **Critical + Failures**: `brr.... ...` (1 blue + 2 red)

## Timing Details
- **Total cycle**: 3 seconds (10 slots × 0.3s each)
- **Each slot**: 0.03s LED on + 0.27s LED off (10% duty cycle)
- **Pattern execution**: Sequential slots with no gaps
- **Status monitoring**: Real-time via ROS2 topic subscriptions
- **Network check**: Every 5 seconds

## Troubleshooting
- **No green LED**: System not running or power issue
- **No status flashes**: Check if Argo service is running
- **Red flashes**: Count indicates number of system failures
- **Blue SOS**: Critical battery - plug in charger immediately
- **All LEDs off**: System shutdown or hardware failure

---
*This guide should be printed and attached to Argo's hatch cover for quick reference during operation.*

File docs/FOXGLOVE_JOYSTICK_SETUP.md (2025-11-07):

# Foxglove Joystick Panel Setup Guide

## Quick Setup Steps

1. **Install the Panel**
   - Open Foxglove Studio
   - Go to Profile menu → Extensions → Extension Marketplace
   - Search for "Joystick" and install

2. **Configure Publishing** (CRITICAL)
   - Open the Joystick panel configuration
   - In the **"Publish" section**:
     - **Publish Mode**: Toggle to **"On"** ⚠️ This is required!
     - **Pub Joy Topic**: Enter `/joy`

3. **Configure Data Source**
   - In the **"Data Source" section**:
     - **Data Source**: Select one of:
       - **"Interactive Display Mode"** - Click/drag on visual joystick (recommended)
       - **"Keyboard Mode"** - Use keyboard keys
       - **"Gamepad Mode"** - Use physical gamepad
     - **DO NOT** use "Subscribed Joy To..." - that's for monitoring only

4. **Verify Configuration**
   - The panel should now show interactive controls (not "waiting for first data")
   - Interacting with the controls should publish to `/joy` topic
   - The simulator will automatically receive and process the commands

## Troubleshooting

### "Waiting for first data" Message

**Cause**: The panel is set to subscribe mode instead of publish mode.

**Fix**:
1. Check **Publish Mode** is set to **"On"** (not "Off")
2. Check **Data Source** is NOT "Subscribed Joy To..."
3. Verify **Pub Joy Topic** is set to `/joy`

### "Tried to publish on topic /joy that has not been advertised before"

**Cause**: ROS2 requires topics to be advertised AND foxglove_bridge needs to see message examples to learn the schema.

**Fix**:
1. Ensure the simulator is running (`asim` command)
2. Wait 3-5 seconds for the simulator bridge to publish 3 schema messages, then it stops
3. Verify the topic exists:
   ```bash
   ros2 topic list | grep joy
   ros2 topic info /joy
   ```
4. **Important**: The simulator publishes 3 initial messages then stops. After that, Foxglove should be able to publish.
5. If still can't publish:
   - Check Data Source is NOT "Subscribed Joy To..." (that disables publish mode)
   - Data Source must be "Interactive Display Mode", "Keyboard Mode", or "Gamepad Mode"
   - If buttons are grayed out, the panel is in subscribe-only mode - change Data Source
   - Try refreshing the Foxglove connection
   - Wait a few more seconds after simulation starts

### Can't See /joy Topic Rate in Foxglove

**Cause**: The simulator only publishes 3 initial messages then stops. After that, the topic only has data when YOU publish from Foxglove.

**This is expected behavior**:
- The simulator publishes 3 messages at startup to teach foxglove_bridge the schema
- Then it stops publishing
- You should see messages when you move the joystick controls in Foxglove
- You can verify by watching: `ros2 topic echo /joy` - should see YOUR messages when you interact with the panel

### Controls Not Responding / Publish Mode Buttons Grayed Out

**Possible causes**:
1. **Data Source is in Subscribe Mode** - This DISABLES publish mode
   - **Fix**: Change Data Source from "Subscribed Joy To..." to:
     - "Interactive Display Mode" (recommended)
     - "Keyboard Mode" 
     - "Gamepad Mode"
2. **Publish Mode is Off** - Enable it in Publish section (only available if Data Source is correct)
3. **Wrong Data Source** - Must be Interactive/Keyboard/Gamepad mode (NOT Subscribe mode)
4. **Topic mismatch** - Verify Pub Joy Topic is `/joy`
5. **Topic not fully advertised** - Wait a few seconds after simulation starts

### Verify It's Working

From your ROS2 terminal (where simulation is running):

```bash
# Check if /joy topic exists and has a publisher
ros2 topic info /joy

# Watch messages being published (should update when you move controls)
timeout 10 ros2 topic echo /joy

# Check simulator is receiving
ros2 topic echo /rudder_sail_radio
```

## Configuration Reference

### Publish Section
- **Publish Mode**: Must be **"On"** for the panel to send commands
- **Pub Joy Topic**: `/joy` (this is what the simulator subscribes to)
- **Joy Frame ID**: Can be left empty

### Data Source Section
- **Data Source**: Choose input method
  - **Interactive Display Mode**: Click/touch the visual joystick display
  - **Keyboard Mode**: Map keyboard keys to joystick axes
  - **Gamepad Mode**: Use physical gamepad/controller
- **Subsc. Joy Topic**: Only needed if using Subscribe mode (not recommended for control)

### Display Section
- **Display Mode**: "Auto-Generated" works well
- **Theme/Mapping**: Can be customized as needed

## How It Works

1. You interact with the Joystick panel (mouse, keyboard, or gamepad)
2. Panel publishes `sensor_msgs/msg/Joy` messages to `/joy` topic
3. Simulator bridge (`argo_unified_simulator_bridge.py`) subscribes to `/joy`
4. Bridge converts Joy messages to rudder/sail control (Vector3)
5. Control is applied to the simulator

## Axis Mapping

Default mapping in the simulator bridge:
- **Axis 0** → Rudder (-1 = left, +1 = right)
- **Axis 1** → Sail (-1 = in, +1 = out, inverted)

You can customize this with ROS2 parameters when starting the simulator.

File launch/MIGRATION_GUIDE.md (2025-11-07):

# Migration Guide: Custom Lifecycle Manager → Standard ROS2 Launch

## Overview

This guide describes migrating from the custom `argo_lifecycle_manager.py` to standard ROS2 launch system while maintaining equivalent functionality.

## Key Benefits

1. **Standard ROS2**: Uses `ros2 launch` - the standard ROS2 way to start nodes
2. **Continuous Health Monitoring**: Health monitor node provides real-time status
3. **Systemd Integration**: Still works reliably at boot
4. **Human-Readable Config**: YAML configuration file (no compilation)
5. **Better Tooling**: Standard ROS2 commands work (`ros2 node list`, `ros2 topic list`, etc.)

## Architecture Changes

### Before (Custom)
```
systemd service → argo_lifecycle_manager.py → subprocess.Popen() → nodes
                                 ↓
                          Status reporting via Python
```

### After (Standard)
```
systemd service → ros2 launch → argo_launch.py → nodes
              ↓
         argo_health_monitor.py (monitors all nodes)
              ↓
         /argo/health/status service
              ↓
         argo_status.py (reports status)
```

## Components

### 1. `argo_nodes.yaml` - Node Configuration
Human-readable YAML file defining all nodes:
- Node names and executables
- Required vs optional nodes
- Critical vs non-critical nodes
- Simulation mode nodes

### 2. `argo_launch.py` - ROS2 Launch File
Standard ROS2 launch file using Python launch API:
- Loads `argo_nodes.yaml`
- Launches nodes based on mode (normal/simulation)
- Handles respawn for non-critical nodes
- Outputs to systemd journal

### 3. `argo_health_monitor.py` - Health Monitor Node
ROS2 node that continuously monitors node health:
- Checks node status every 2 seconds
- Publishes health status on `/argo/health/status` topic
- Provides `/argo/health/status` service for queries
- Tracks which nodes are running/stopped

### 4. `argo_status.py` - Status Reporter
Command-line tool for status reporting:
- Uses standard ROS2 commands (`ros2 node list`, `ros2 service call`)
- Queries health monitor service
- Provides full and quick status modes

### 5. `argo_launch_standard.service` - Systemd Service
Updated systemd service file:
- Uses `ros2 launch` instead of custom Python script
- Starts health monitor as background process
- Restarts on failure (standard systemd behavior)

## Migration Steps

### Step 1: Install New Components

The new files are already created:
- `launch/argo_nodes.yaml`
- `launch/argo_launch.py`
- `launch/argo_health_monitor.py`
- `launch/argo_status.py`
- `launch/argo_launch_standard.service`

### Step 2: Update Shell Aliases

Update `dotfiles/.bash_aliases` to use new status command:

```bash
# Old:
alias as='$ARGO_DIR/launch/argo_status.sh'

# New:
alias as='python3 $ARGO_DIR/launch/argo_status.py'
alias asq='python3 $ARGO_DIR/launch/argo_status.py --quick'  # Quick status
```

### Step 3: Update Shell Functions

Update `dotfiles/.bashrc` to use new status function:

```bash
# Old:
argo_status() {
    python3 "$ARGO_DIR/launch/argo_lifecycle_manager.py" status
}

# New:
argo_status() {
    python3 "$ARGO_DIR/launch/argo_status.py"
}

argo_quick_status() {
    python3 "$ARGO_DIR/launch/argo_status.py" --quick
}
```

### Step 4: Switch Systemd Service

1. Stop old service:
   ```bash
   sudo systemctl stop argo_launch.service
   ```

2. Install new service:
   ```bash
   sudo cp launch/argo_launch_standard.service /etc/systemd/system/
   sudo systemctl daemon-reload
   ```

3. Start new service:
   ```bash
   sudo systemctl start argo_launch_standard.service
   sudo systemctl enable argo_launch_standard.service
   ```

4. Optional: Remove old service:
   ```bash
   sudo systemctl disable argo_launch.service
   ```

### Step 5: Test New System

1. Check service status:
   ```bash
   sudo systemctl status argo_launch_standard.service
   ```

2. Check ROS2 nodes:
   ```bash
   ros2 node list
   ```

3. Check health status:
   ```bash
   python3 launch/argo_status.py
   ros2 service call /argo/health/status std_srvs/srv/Trigger
   ```

4. Test quick status:
   ```bash
   python3 launch/argo_status.py --quick
   ```

## Configuration

### Adding New Nodes

Edit `launch/argo_nodes.yaml`:

```yaml
nodes:
  - name: my_new_node
    executable: nodes/my_new_node.py
    required: false
    critical: false
    description: "My new node description"
```

No code changes needed - just edit YAML and restart service.

### Node Configuration Options

- `name`: ROS2 node name (as it appears in `ros2 node list`)
- `executable`: Path to Python script (relative to ARGO_DIR)
- `required`: If false, system continues if node fails
- `critical`: If true, missing node is considered system failure
- `description`: Human-readable description
- `special`: If true, requires custom launch handling (e.g., `ros2 run`)

## Compatibility

### Preserved Functionality

✅ Systemd service at boot  
✅ Status reporting (full and quick)  
✅ Shell aliases and functions  
✅ Node health monitoring  
✅ Simulation mode support  
✅ Excluded nodes (battery, BNO085)  

### Improvements

✅ Standard ROS2 commands work  
✅ Better integration with ROS2 tooling  
✅ Health monitoring is continuous (not just on status check)  
✅ Human-readable configuration (no compilation)  
✅ Easier to add/remove nodes  

### Removed (No Longer Needed)

❌ Custom lifecycle manager Python code  
❌ Direct subprocess management  
❌ Custom process tracking  

## Troubleshooting

### Health Monitor Not Starting

Check if ROS2 is available:
```bash
ros2 node list
```

If health monitor isn't running, start manually:
```bash
source /opt/ros/humble/setup.bash
python3 launch/argo_health_monitor.py
```

### Nodes Not Launching

Check launch file syntax:
```bash
ros2 launch launch/argo_launch.py --show-args
```

Check systemd logs:
```bash
sudo journalctl -u argo_launch_standard.service -f
```

### Status Command Fails

Ensure health monitor is running:
```bash
ros2 service list | grep health
```

If missing, health monitor needs to be started (should be automatic via systemd).

## Rollback Plan

If issues occur, rollback to old system:

1. Stop new service:
   ```bash
   sudo systemctl stop argo_launch_standard.service
   ```

2. Start old service:
   ```bash
   sudo systemctl start argo_launch.service
   ```

3. Restore old aliases in `dotfiles/.bash_aliases` and `dotfiles/.bashrc`

## Next Steps

1. Test thoroughly in development environment
2. Update documentation references
3. Update any scripts that call lifecycle manager directly
4. Consider adding more health metrics to health monitor
5. Consider adding ROS2 lifecycle node support for graceful shutdown

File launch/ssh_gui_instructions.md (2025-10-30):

# Running Argo Status GUI Remotely via SSH

## 🖥️ Method 1: SSH X11 Forwarding (Recommended)

### From your local machine:

```bash
# Connect with X11 forwarding enabled
ssh -X orangepi@YOUR_ORANGE_PI_IP

# Or for better performance with compression
ssh -X -C orangepi@YOUR_ORANGE_PI_IP

# For trusted connections (faster but less secure)
ssh -Y orangepi@YOUR_ORANGE_PI_IP
```

### Once connected, run the GUI:
```bash
cd ~/argo/launch
./argo_status_gui.sh
```

### Troubleshooting X11 Forwarding:

**On your local machine (client):**
```bash
# Make sure X11 forwarding is enabled in SSH config
echo "ForwardX11 yes" >> ~/.ssh/config

# For macOS, install XQuartz first:
# brew install --cask xquartz
# Then restart and try again
```

**On Orange Pi (server):**
```bash
# Enable X11 forwarding in SSH daemon
sudo nano /etc/ssh/sshd_config

# Add/uncomment these lines:
X11Forwarding yes
X11DisplayOffset 10
X11UseLocalhost yes

# Restart SSH service
sudo systemctl restart sshd

# Install X11 utilities if missing
sudo apt-get install xauth xorg-dev
```

---

## 🌐 Method 2: VNC Server (Better for slow connections)

### Install and setup VNC on Orange Pi:
```bash
# Install VNC server
sudo apt-get update
sudo apt-get install tightvncserver

# Start VNC server (first time setup)
vncserver :1

# You'll be prompted to set a password
```

### Create VNC startup script:
```bash
# Create vnc startup script
cat > ~/.vnc/xstartup << 'EOF'
#!/bin/bash
xrdb $HOME/.Xresources
startxfce4 &
EOF

chmod +x ~/.vnc/xstartup

# Restart VNC with desktop environment
vncserver -kill :1
vncserver :1 -geometry 1024x768 -depth 24
```

### Connect from your local machine:
```bash
# Create SSH tunnel for VNC
ssh -L 5901:localhost:5901 orangepi@YOUR_ORANGE_PI_IP

# Then connect with VNC viewer to: localhost:5901
# Or use browser-based VNC: http://localhost:5901
```

### Run GUI in VNC session:
```bash
cd ~/argo/launch
./argo_status_gui.sh
```

---

## 🔧 Method 3: Web-based Alternative

Since you already have Foxglove setup, consider creating a web-based status dashboard:

```bash
# Create simple web status server
cat > ~/argo/launch/web_status.py << 'EOF'
#!/usr/bin/env python3
"""Simple web status server for remote monitoring"""

from http.server import HTTPServer, BaseHTTPRequestHandler
import json
# Note: argo_status_check.py is deprecated, use argo_lifecycle_manager.py instead
# from argo_status_check import OptimizedArgoStatusChecker

class StatusHandler(BaseHTTPRequestHandler):
    def do_GET(self):
        if self.path == '/status':
            checker = OptimizedArgoStatusChecker()
            ros_info = checker.check_ros_nodes_fast()
            sys_info = checker.get_system_info_fast()
            
            status = {
                'ros_info': ros_info,
                'sys_info': sys_info,
                'timestamp': str(datetime.now())
            }
            
            self.send_response(200)
            self.send_header('Content-type', 'application/json')
            self.end_headers()
            self.wfile.write(json.dumps(status, indent=2).encode())
        else:
            self.send_response(404)
            self.end_headers()

if __name__ == '__main__':
    server = HTTPServer(('0.0.0.0', 8080), StatusHandler)
    print("Status server running on http://YOUR_PI_IP:8080/status")
    server.serve_forever()
EOF

chmod +x ~/argo/launch/web_status.py
```

---

## ⚡ Quick Test Commands

### Test X11 forwarding:
```bash
# After SSH with -X, test with:
xclock
# If a clock window appears, X11 forwarding works!
```

### Test GUI import:
```bash
ssh -X orangepi@YOUR_IP
cd ~/argo/launch
python3 -c "import tkinter; tkinter.Tk().mainloop()"
# Should show empty window
```

---

## 🎯 Recommendations

1. **For fast networks**: Use SSH X11 forwarding (Method 1)
2. **For slow/unreliable networks**: Use VNC (Method 2)  
3. **For monitoring only**: Use web status API (Method 3)
4. **For advanced users**: Combine with your existing Foxglove setup

The GUI will work seamlessly over any of these methods while maintaining all its real-time monitoring capabilities!

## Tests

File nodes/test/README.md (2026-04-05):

# LoRa Hardware Diagnostic Tools

This directory contains hardware diagnostic scripts for testing and debugging the SX1276 LoRa module.

## Tools

### test_lora_spi.py

Comprehensive SPI and GPIO diagnostic tool for the LoRa module.

**Hardware Tested:**
- SPI communication (bus 1, device 0)
- GPIO control (CS, RST, IRQ pins)
- SX1276 register access
- Module reset sequence

**Test Modes:**

```bash
# Basic SPI communication test (default)
python3 test_lora_spi.py basic

# GPIO pin toggling for oscilloscope verification
python3 test_lora_spi.py pins

# Reset sequence testing
python3 test_lora_spi.py reset

# Repeated version register reads
python3 test_lora_spi.py version

# Multiple register dump
python3 test_lora_spi.py regs

# Run all tests
python3 test_lora_spi.py all
```

**Expected Results:**
- Version register (0x42) should read **0x12** for SX1276
- OpMode register (0x01) should have valid mode bits
- MISO should show ~3.3V amplitude on oscilloscope
- All GPIO pins should toggle cleanly

**Common Issues:**

| Symptom | Likely Cause | Solution |
|---|---|---|
| Version = 0x00 or 0xFF | No SPI communication | Check wiring, power, module orientation |
| Version = 0x3F | Wrong chip or mode | Check if module is in correct state, verify power |
| Low MISO amplitude | Wiring issue | Check header adapter, verify pin connections |
| No GPIO activity | GPIO not configured | Check device tree overlays, udev rules |

**Hardware Configuration:**

```
Orange Pi Pin -> LoRa Module
SDA.1 / Pin 3 (GPIO 264) -> CS   (Chip Select)
PI0  (GPIO 256) -> RST  (Reset)
PI15 (GPIO 271) -> DIO0 (Interrupt)
SPI1_MOSI       -> MOSI
SPI1_MISO       -> MISO
SPI1_CLK        -> SCK
3.3V            -> VCC
GND             -> GND
```

## Usage Tips

### For Hardware Debugging
1. Start with `basic` test to verify communication
2. Use `pins` test with oscilloscope to verify signal integrity
3. Use `version` test to check for intermittent issues
4. Use `regs` test to see full module state

### For Oscilloscope Verification
```bash
# Run pin toggle test - watch CS and RST on scope
python3 test_lora_spi.py pins

# Look for:
# - Clean 3.3V logic levels
# - No ringing or overshoot
# - Proper timing between transitions
```

### If Module Not Responding
1. Check power: should be 3.3V ±0.1V
2. Check antenna: must be connected (even for local testing)
3. Check wiring: MISO/MOSI not swapped, correct pin adapter
4. Reset module: power cycle if necessary
5. Verify SPI enabled: check `/dev/spidev1.0` exists

## Integration with Main LoRa Node

The main LoRa node is at `../lora.py`. These test scripts use the same:
- SPI configuration (bus 1, device 0, mode 0, 1 MHz)
- GPIO pins (264, 256, 271)
- Register addresses (0x42 version, 0x01 opmode, etc.)

If these test scripts work but `lora.py` doesn't, the issue is in the higher-level logic (modes, packet handling, etc.).

## Troubleshooting

### Version Register Shows 0x3F

This is what you're currently seeing. Possible causes:

1. **Module in wrong mode**
   - Module might be in continuous TX/RX mode
   - Try resetting with `reset` test mode
   - Power cycle the Orange Pi

2. **Wrong chip type**
   - SX1276 should return 0x12
   - SX1262 has different register map
   - Verify module label and datasheet

3. **Chip not responding properly**
   - Check if register 0x01 (OpMode) is readable
   - Try writing and reading back OpMode
   - May need power cycle

4. **Wiring issue**
   - MISO might not be connected properly
   - Check with oscilloscope in `pins` mode
   - Verify continuity with multimeter

### Commands to Try

```bash
# Quick diagnostic
cd ~/argo/nodes/test
python3 test_lora_spi.py basic

# If basic test shows 0x3F, try reset
python3 test_lora_spi.py reset

# Check if value is stable
python3 test_lora_spi.py version

# Full register dump to see module state
python3 test_lora_spi.py regs
```

## See Also

- `../lora.py` - Main LoRa ROS2 node
- `../.cursor/rules/argo-lora-communication.mdc` - Full LoRa system documentation
- [`../../docs/README-lora-to-shore.md`](../../docs/README-lora-to-shore.md) - LoRa hardware, link parameters, Waveshare AT notes

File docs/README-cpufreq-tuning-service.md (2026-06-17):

# CPU Frequency Tuning Service

## Overview

Argo’s Orange Pi Zero 2W (Allwinner H618) uses **two independent DVFS layers**:

| Layer | Mechanism | Trigger | Purpose |
|---|---|---|---|
| **Argo (this service)** | `conservative` cpufreq governor | CPU load | Less aggressive scaling than stock `ondemand`; reduces sustained max-frequency time |
| **Kernel thermal** | `cpufreq-cpu0` cooling device | CPU temp ≥ 85°C | Caps `scaling_max_freq` when the passive thermal trip is crossed |

This document covers the **Argo cpufreq-tuning service** and how it interacts with kernel thermal throttling. For sysfs OPP/voltage details, see [dvfs_userspace_access.md](dvfs_userspace_access.md). For temperature logging and alerts, see [README-thermal-monitoring.md](README-thermal-monitoring.md).

**Last verified on hardware:** 2026-06-17 (kernel 6.1.31-sun50iw9).

---

## Problem Addressed

The original Armbian image used an **ondemand** governor with aggressive parameters:

- `up_threshold: 25%` — CPU scaled to maximum frequency at only 25% usage
- Caused sustained 1512 MHz during memory-intensive work (e.g. Cursor agent sessions)
- Contributed to thermal stress and occasional system instability

## Solution

`cpufreq-tuning.service` runs once at boot and applies a **conservative** governor with higher scale-up thresholds.

### Governor: Conservative

- More gradual frequency scaling under moderate load
- Still reaches 1512 MHz when all cores are busy
- Does **not** temperature-limit the CPU — that is handled separately by kernel thermal cooling

---

## Available CPU Frequencies (OPP)

Eight discrete levels (kHz values from `scaling_available_frequencies`):

| MHz | kHz | Notes |
|-----|-----|---|
| 480 | 480000 | Minimum |
| 600 | 600000 | |
| 792 | 792000 | |
| 1008 | 1008000 | |
| 1200 | 1200000 | Typical kernel thermal cap (cooling state 3/7) |
| 1344 | 1344000 | |
| 1416 | 1416000 | |
| 1512 | 1512000 | Maximum |

Voltage per OPP (speed bin 0): see [dvfs_userspace_access.md](dvfs_userspace_access.md).

---

## Conservative Governor Parameters

### Values set by `/usr/local/bin/cpufreq-tuning.sh`

| Parameter | Script writes | Description |
|---|---|---|
| `scaling_governor` | `conservative` | All CPU cores |
| `up_threshold` | 80 | Scale up only when average load ≥ 80% |
| `down_threshold` | 20 | Scale down when load < 20% |
| `sampling_rate` | 100000 μs | 100 ms sample interval |
| `sampling_down_factor` | 1 | Same speed scaling up and down |
| `ignore_nice_load` | 0 | Include nice processes in load |
| `freq_step` | 0 | Kernel default step (observed as 5 at runtime) |

### Runtime values observed (2026-06-17)

After boot, verify live values — some may differ from what the script writes (e.g. if `cpufrequtils` or the kernel adjusts them later):

```bash
cat /sys/devices/system/cpu/cpu*/cpufreq/scaling_governor
cat /sys/devices/system/cpu/cpufreq/conservative/{up_threshold,down_threshold,sampling_rate,freq_step}
```

Observed at last check: governor `conservative`, `up_threshold=80`, `down_threshold=20`, `sampling_rate=10000`, `freq_step=5`.

---

## Kernel Thermal Throttling (separate from this service)

The cpufreq-tuning service does **not** configure thermal limits. The kernel manages those via `thermal_zone2` (`cpu-thermal`):

| Setting | Value |
|---|---|
| Policy | `fair_share` |
| Passive trip | **85°C** (`trip_point_0_temp`) |
| Hysteresis | **2°C** (throttle above 85°C, release below ~83°C) |
| Critical trip | 100°C |
| Cooling device | `cpufreq-cpu0`, states 0–7 |

### Cooling state → max frequency cap

When the passive trip is crossed, the kernel sets `scaling_max_freq` according to cooling state:

| State | Max frequency |
|---|---|
| 0/7 | 1512 MHz (no thermal cap) |
| 1/7 | 1416 MHz |
| 2/7 | 1344 MHz |
| 3/7 | **1200 MHz** |
| 4/7 | 1008 MHz |
| 5/7 | 792 MHz |
| 6/7 | 600 MHz |
| 7/7 | 480 MHz |

Under sustained 4-core stress (2026-06-17, `stress-ng --cpu 4`), behavior was:

- CPU temp **81.9 – 87.1°C** (mean 84.6°C)
- **~52%** of 1 Hz samples showed cooling state **3/7** at **1200 MHz**
- **~35%** at **1512 MHz** (cooling state 0/7)
- Deeper states (4–7) were **not** observed — small overshoot above 85°C plus 2°C hysteresis causes a **~2 s bang-bang oscillation** between 1512 and 1200 MHz rather than sustained deep throttling

The 30-second `argo_thermal_monitor` logs round to integer °C and do not record frequency or cooling state, so they under-report this oscillation.

### Quick thermal + frequency check

```bash
# One-shot
echo "temp=$(($(cat /sys/class/thermal/thermal_zone2/temp)/1000))°C \
  cooling=$(cat /sys/class/thermal/cooling_device0/cur_state)/7 \
  freq=$(($(cat /sys/devices/system/cpu/cpu0/cpufreq/scaling_cur_freq)/1000))MHz \
  max=$(($(cat /sys/devices/system/cpu/cpu0/cpufreq/scaling_max_freq)/1000))MHz"

# 1 Hz for 15 s (good for seeing bang-bang throttling)
for i in $(seq 15); do
  printf '%s  %5.1f°C  %s/7  %4s MHz\n' "$(date +%H:%M:%S)" \
    "$(echo "scale=1; $(cat /sys/class/thermal/thermal_zone2/temp)/1000" | bc)" \
    "$(cat /sys/class/thermal/cooling_device0/cur_state)" \
    "$(($(cat /sys/devices/system/cpu/cpu0/cpufreq/scaling_cur_freq)/1000))"
  sleep 1
done
```

Persistent thermal logs: `/var/log.hdd/persistent/thermal-YYYYMMDD.log` (see [README-persistent-logging.md](README-persistent-logging.md)).

---

## Files

**Note:** The service and script are installed on the robot filesystem only; they are **not** tracked in the argo git repo.

| Item | Path |
|---|---|
| Systemd unit | `/etc/systemd/system/cpufreq-tuning.service` |
| Boot script | `/usr/local/bin/cpufreq-tuning.sh` |
| Service log | `/var/log/cpufreq-tuning.log` |

### Boot script (reference)

```bash
#!/bin/bash
for cpu in /sys/devices/system/cpu/cpu[0-9]*/cpufreq/scaling_governor; do
    echo conservative > "$cpu" 2>/dev/null || true
done
echo 80  > /sys/devices/system/cpu/cpufreq/conservative/up_threshold
echo 20  > /sys/devices/system/cpu/cpufreq/conservative/down_threshold
echo 100000 > /sys/devices/system/cpu/cpufreq/conservative/sampling_rate
echo 1  > /sys/devices/system/cpu/cpufreq/conservative/sampling_down_factor
echo 0  > /sys/devices/system/cpu/cpufreq/conservative/ignore_nice_load
echo 0  > /sys/devices/system/cpu/cpufreq/conservative/freq_step
```

### Dependencies

- **After:** `cpufrequtils.service`
- **Type:** oneshot, `RemainAfterExit=yes`
- **Install:** `WantedBy=multi-user.target` (enabled on current robot)

---

## Usage

### Service management

```bash
sudo systemctl status cpufreq-tuning.service
sudo systemctl start cpufreq-tuning.service   # re-apply settings
sudo systemctl disable cpufreq-tuning.service # stop applying at boot
```

### Verify configuration

```bash
cat /sys/devices/system/cpu/cpu*/cpufreq/scaling_governor
cat /sys/devices/system/cpu/cpu*/cpufreq/scaling_cur_freq
cat /sys/devices/system/cpu/cpu0/cpufreq/scaling_available_frequencies
cat /sys/class/thermal/cooling_device0/{cur_state,max_state}
```

### Monitor under load

```bash
# Optional 1-minute stress + sampling (requires stress-ng)
stress-ng --cpu 4 --timeout 60s &
for i in $(seq 60); do
  printf '%s  %5.1f°C  %s/7  %4s MHz\n' "$(date +%H:%M:%S)" \
    "$(echo "scale=1; $(cat /sys/class/thermal/thermal_zone2/temp)/1000" | bc)" \
    "$(cat /sys/class/thermal/cooling_device0/cur_state)" \
    "$(($(cat /sys/devices/system/cpu/cpu0/cpufreq/scaling_cur_freq)/1000))"
  sleep 1
done
wait
```

---

## Monitoring integration

| Service | Role |
|---|---|
| `cpufreq-tuning.service` | Boot-time governor policy |
| `argo_thermal_monitor.service` | Logs GPU/VE/CPU/DDR temps every 30 s; warns at >80°C |
| `orangepi-monitor.service` (optional) | Logs MHz, load, temp, cooling state (`C.St.`) every ~5 s |

---

## Troubleshooting

### Governor not conservative after boot

```bash
sudo systemctl status cpufreq-tuning.service cpufrequtils.service
sudo /usr/local/bin/cpufreq-tuning.sh
cat /sys/devices/system/cpu/cpu*/cpufreq/scaling_governor
```

### High temps but frequency stays at 1512 MHz

Expected between throttle bursts: thermal hysteresis releases the cap quickly. Sample at **1 Hz** and check `cooling_device0/cur_state`, not just the thermal log.

### Reverting to stock ondemand

```bash
sudo systemctl disable cpufreq-tuning.service
echo ondemand | sudo tee /sys/devices/system/cpu/cpu*/cpufreq/scaling_governor
sudo systemctl restart cpufrequtils
```

---

## Performance impact

- **Positive:** Less time at max frequency under moderate load; better stability during sustained desktop/agent work
- **Trade-off:** Slower response when load ramps gradually (80% threshold)
- **Under full CPU stress:** Still reaches 1512 MHz whenever thermal cooling is at state 0/7
- **Thermal ceiling:** Kernel may cap at 1200 MHz intermittently above 85°C regardless of governor

---

## Related documentation

- [dvfs_userspace_access.md](dvfs_userspace_access.md) — OPP table, voltage rails, sysfs read/write
- [README-thermal-monitoring.md](README-thermal-monitoring.md) — `argo_thermal_monitor` logging
- [README-persistent-logging.md](README-persistent-logging.md) — `/var/log.hdd/persistent/` log layout

---

## History

| Date | Change |
|---|---|
| 2025-09-25 | Initial `cpufreq-tuning.service` — conservative governor to reduce hangs during Cursor agent work |
| 2026-06-17 | Documented kernel thermal layer, OPP table, cooling-state mapping, and observed bang-bang throttling behavior |

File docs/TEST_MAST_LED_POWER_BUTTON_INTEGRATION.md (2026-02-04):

# Testing Mast LED and Power Button Integration

This describes how to verify coordination between the **mast LED node** (`argo_mast_leds.py`) and the **power control node** (`argo_power_control.py`): the mast head LEDs mirror the power button LED state via ROS2 topics.

**Note:** The power button has **RGB only** (no white). The mast has **RGBW**. Mirroring updates only R, G, B on the mast; the white channel is not driven by the power button and stays off unless something else publishes to `/mastled_w` or `/mastled_rgbw`.

## Prerequisites

- **Power control** runs as a systemd service: `argo_power_control.service` (publishes `/argo/power_button/rgb` and `/argo/power_button/pattern`).
- **Mast LEDs** run as a regular ROS node (lifecycle manager or standalone): subscribes to those topics and drives the PCA9632 on the wind sensor PCB.

## Quick integration test (manual RGB)

1. Start Argo so both are running:
   - `al` (or start `argo_launch` service) so `mastleds_node` is running.
   - Ensure `argo_power_control.service` is running: `sudo systemctl status argo_power_control`.

2. Run the test script (publishes RGB to the same topic power_control uses; mast should mirror):
   ```bash
   source /opt/ros/humble/setup.bash
   bash /home/orangepi/argo/scripts/test_mast_led_power_button_integration.sh
   ```
   Watch the **mast head LEDs**: they should cycle red → green → blue → off (a few seconds each). White is not tested here because the power button has no white channel.

3. Or publish once manually:
   ```bash
   source /opt/ros/humble/setup.bash
   ros2 topic pub --once /argo/power_button/rgb geometry_msgs/Vector3 "{x: 1.0, y: 0.0, z: 0.0}"
   ```
   Mast should show **red**. Try `x: 0, y: 1, z: 0` for green, `x: 0, y: 0, z: 1` for blue.

## Testing pattern mirroring (heartbeat)

1. With Argo running (power_control service + mastleds node), **press and hold the power button** to start the heartbeat pattern on the power button LEDs.
2. Power control publishes `/argo/power_button/pattern` (JSON with category, pattern string, timing).
3. **Mast head LEDs** should show the same heartbeat pattern (e.g. green blinks) in sync.

## Topics

| Topic | Type | Publisher | Subscriber |
|---|---|---|---|
| `/argo/power_button/rgb` | `geometry_msgs/Vector3` | power_control | mastleds (RGB mirror) |
| `/argo/power_button/pattern` | `std_msgs/String` | power_control | mastleds (pattern mirror) |

## Troubleshooting

- **Mast LEDs don’t change when publishing RGB**
  - Check mastleds node is running: `ros2 node list` should show `mastleds_node`.
  - Check subscription: `ros2 topic info /argo/power_button/rgb`.
- **No pattern on mast when holding power button**
  - Ensure power_control service is running and publishing: `ros2 topic echo /argo/power_button/pattern`.
  - Mast node must be running and subscribed to `/argo/power_button/pattern`.

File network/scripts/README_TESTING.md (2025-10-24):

# WiFi Reconnection Testing

This directory contains comprehensive testing tools for the Argo WiFi reconnection system.

## Test Scripts

### `test_wifi_reconnection.sh`
**Main test script** that simulates network disconnection scenarios and monitors system behavior.

**Features:**
- **3-minute duration** with comprehensive testing phases
- **Background execution** - continues even if SSH connection is lost
- **Automatic cleanup** - always restores tobi-wlan connection
- **Power control monitoring** - tracks LED status indicators
- **Comprehensive logging** - detailed logs for analysis

**Test Phases:**
1. **Baseline Monitoring (30s)** - Monitor current system state
2. **Disconnection Test** - Simulate tobi-wlan disconnection
3. **Fallback Verification** - Verify uzh-iot takes over
4. **Restoration Test** - Restore tobi-wlan connection
5. **Final Monitoring (30s)** - Verify system stability

### `run_wifi_test.sh`
**Test launcher** that provides easy management of the test process.

**Commands:**
- `start` - Start test in background
- `status` - Check test progress
- `logs` - Watch live test output
- `stop` - Stop running test
- `results` - Show test results

## Usage

### Quick Start
```bash
# Start test in background
make test-wifi-reconnection

# Check progress
make wifi-test-status

# View results
make wifi-test-results
```

### Manual Usage
```bash
# Start test
./network/scripts/run_wifi_test.sh start

# Monitor progress
./network/scripts/run_wifi_test.sh status

# Watch live logs
./network/scripts/run_wifi_test.sh logs

# View results
./network/scripts/run_wifi_test.sh results
```

### Direct Test Execution
```bash
# Run test directly (foreground)
sudo ./network/scripts/test_wifi_reconnection.sh
```

## Expected Behavior

### Network Switching
1. **Initial State**: Connected to tobi-wlan
2. **Disconnection**: tobi-wlan goes down
3. **Fallback**: uzh-iot takes over automatically
4. **Restoration**: tobi-wlan reconnects when available
5. **Final State**: Back on tobi-wlan

### Power Control LED Indicators
- **WiFi Loss**: Alternating red/green LED pattern
- **WiFi Restored**: Return to normal LED pattern
- **Monitoring**: All LED changes logged

### Logging
- **Test Log**: `/var/log.hdd/persistent/wifi-reconnection-test.log`
- **Power Control Log**: `/var/log.hdd/persistent/argo-power-control.log`
- **WiFi Reconnection Log**: `/var/log.hdd/persistent/wifi-reconnect.log`

## Safety Features

### Automatic Cleanup
The test script includes a cleanup function that:
- **Always runs** - even if script is interrupted
- **Restores tobi-wlan** - ensures remote access
- **Multiple retry attempts** - handles connection failures
- **Status verification** - confirms connection is active

### Error Handling
- **Graceful failures** - continues testing even if some steps fail
- **Comprehensive logging** - all errors are recorded
- **Timeout protection** - prevents hanging on network operations
- **Process monitoring** - tracks background processes

## Test Scenarios

### Scenario 1: Normal Operation
- Start with tobi-wlan connected
- Simulate disconnection
- Verify uzh-iot fallback
- Restore tobi-wlan
- Verify system stability

### Scenario 2: SSH Disconnection
- Test runs in background
- SSH connection can be lost
- Test continues independently
- tobi-wlan automatically restored
- Remote access maintained

### Scenario 3: Network Unavailability
- Test handles missing networks gracefully
- Logs all network states
- Continues monitoring
- Restores preferred connection when available

## Monitoring and Analysis

### Real-time Monitoring
```bash
# Watch test progress
make wifi-test-status

# Monitor live logs
./network/scripts/run_wifi_test.sh logs

# Check power control status
systemctl status argo_power_control.service
```

### Post-test Analysis
```bash
# View complete test results
make wifi-test-results

# Check WiFi reconnection logs
tail -f /var/log.hdd/persistent/wifi-reconnect.log

# Analyze power control events
grep -E "(WiFi|LED)" /var/log.hdd/persistent/argo-power-control.log
```

## Troubleshooting

### Test Won't Start
- Check if already running: `make wifi-test-status`
- Verify permissions: script needs sudo access
- Check dependencies: NetworkManager must be running

### Test Hangs
- Check network connectivity: `nmcli connection show --active`
- Verify power control service: `systemctl status argo_power_control.service`
- Review logs for error messages

### Connection Not Restored
- Test includes automatic retry logic
- Check manual restoration: `nmcli connection up tobi-wlan`
- Verify network availability: `nmcli device wifi list`

## Integration

### Makefile Integration
- `test-wifi-reconnection` - Start test
- `wifi-test-status` - Check status
- `wifi-test-results` - View results

### System Integration
- Uses existing WiFi reconnection system
- Monitors power control service
- Integrates with NetworkManager
- Logs to persistent storage

## Development

### Extending Tests
- Add new test phases in `test_wifi_reconnection.sh`
- Modify monitoring duration in configuration section
- Add new network scenarios as needed

### Customization
- Adjust test duration: Change `TEST_DURATION` variable
- Modify log locations: Update `LOG_FILE` variables
- Add new monitoring: Extend `monitor_power_control()` function

## Best Practices

### Before Testing
1. Ensure tobi-wlan is available and working
2. Verify uzh-iot is accessible as fallback
3. Check power control service is running
4. Confirm sufficient disk space for logs

### During Testing
1. Don't interrupt the test unnecessarily
2. Monitor via status commands rather than direct SSH
3. Let the test complete its full cycle
4. Trust the automatic cleanup process

### After Testing
1. Review test results thoroughly
2. Check all log files for issues
3. Verify system returned to normal state
4. Document any unexpected behavior

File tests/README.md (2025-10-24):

# Argo Testing Directory

This directory contains various tests for the Argo sailboat system.

## Test Categories

### ROS2 Service Communication Test
Tests to verify that different ROS2 services can communicate with each other via Trigger service calls.

### LoRa Communication Tests
Located in `lora/` subdirectory - testing and analysis scripts for LoRa communication validation.

## Files

- `test_service_server.py` - ROS2 service server that responds to Trigger service calls
- `test_service_client.py` - ROS2 service client that calls the Trigger service
- `test-service-server.service` - Systemd service file for the server
- `test-service-client.service` - Systemd service file for the client
- `test_services.sh` - Test script to install, run, and cleanup the services

## Test Results

✅ **SUCCESS**: The test was completed successfully on 2025-10-05.

### Test Execution Summary

1. **Service Server**: Started successfully and began listening for Trigger service calls
   - Service name: `test_trigger_service`
   - Node name: `test_service_server`
   - Status: Active and running

2. **Service Client**: Successfully called the Trigger service and received response
   - Service call successful: ✅ True
   - Response message: "Test service server responded successfully!"
   - Exit code: 0 (success)

3. **Communication**: Verified bidirectional communication between services
   - Server received and processed the request
   - Client received the expected response
   - Both services logged their interaction properly

## How to Run the Test

### Using the Test Script
```bash
# Install services
./test_services.sh install

# Run the test
./test_services.sh test

# View logs
./test_services.sh logs

# Cleanup
./test_services.sh cleanup
```

### Manual Testing
```bash
# Start server in background
bash -c 'source /opt/ros/humble/setup.bash && python3 test_service_server.py' &

# Run client
bash -c 'source /opt/ros/humble/setup.bash && python3 test_service_client.py'
```

## Technical Details

- **ROS2 Version**: Humble
- **Python Version**: 3.9.13 (system Python)
- **Service Type**: std_srvs/Trigger
- **User**: tobi
- **Environment**: Properly sourced ROS2 setup

## Systemd Integration

The services are configured to run as systemd services under the `tobi` user:

- Server runs as a persistent service (`Type=simple`)
- Client runs as a one-shot service (`Type=oneshot`)
- Proper ROS2 environment sourcing in ExecStart
- Journal logging for debugging

This test confirms that ROS2 services can successfully communicate with each other in the Argo environment, which is essential for the distributed control system architecture.

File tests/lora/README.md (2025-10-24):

# LoRa Testing Scripts

This directory contains testing and analysis scripts for LoRa communication validation.

**Location**: `~/argo/tests/lora/`

## Scripts

### `analyze_latest_lora.py`
**Purpose**: Comprehensive analysis of LoRa communication from ROS bag recordings
**Usage**: `python3 analyze_latest_lora.py [bag_path]`
**Features**:
- Analyzes LoRa RX data, signal strength, and GPS data
- Calculates communication rates and statistics
- Identifies JSON vs binary data packets
- Checks for lora/ prefixed topics (indicates successful shore-side parsing)
- Shows GPS fix samples

### `check_signal_strength.py`
**Purpose**: Detailed analysis of LoRa signal strength data
**Usage**: `python3 check_signal_strength.py [bag_path]`
**Features**:
- Extracts signal strength statistics (min, max, average)
- Categorizes signals by quality (good ≥-80 dBm, fair -90 to -80 dBm, poor <-90 dBm)
- Shows signal strength samples and distribution

### `plot_gps_lora_simple.py`
**Purpose**: Creates GPS track visualization with LoRa ping reception points
**Usage**: `python3 plot_gps_lora_simple.py [bag_path]`
**Features**:
- Plots GPS track as blue line
- Overlays LoRa ping points color-coded by signal strength
- Shows signal strength over time
- Calculates approximate distance traveled
- Saves plot as `/tmp/gps_lora_track.png`
- **Verbose progress tracking** - shows processing status every 5000 messages

## Dependencies

All scripts require:
- `rosbag2_py` (ROS2 bag reading)
- `matplotlib` (for plotting script)
- `numpy` (for plotting script)

Install with:
```bash
pip install matplotlib numpy
```

## Example Usage

```bash
# Navigate to the lora test directory
cd ~/argo/tests/lora

# Analyze the latest recording
python3 analyze_latest_lora.py ~/argo/bags/argo_20251024_122903

# Check signal strength statistics
python3 check_signal_strength.py ~/argo/bags/argo_20251024_122903

# Create GPS + LoRa visualization
python3 plot_gps_lora_simple.py ~/argo/bags/argo_20251024_122903
```

## Test Results Summary

### Latest Test (argo_20251024_122903)
- **Duration**: 338 seconds (5.6 minutes)
- **LoRa RX Rate**: 0.96 msg/sec (325 messages)
- **Signal Strength Rate**: 0.51 msg/sec (171 measurements)
- **GPS Fix Rate**: 0.39 msg/sec (133 valid fixes)
- **Data Quality**: All samples were valid JSON ping packets
- **Signal Quality**: 92.4% poor signals (<-90 dBm), but communication still worked
- **GPS Location**: Switzerland (Lat=47.399052, Lon=8.546594, Alt=~152m)

### Key Findings
- ✅ Bidirectional LoRa communication working
- ✅ Valid JSON packets being received
- ✅ GPS fix working and providing position data
- ⚠️ Most signals are poor quality but communication still functional
- ❌ No lora/ prefixed topics found (shore-side JSON parsing may not be publishing to ROS)

## Notes

- Scripts are designed to work with ROS2 bag files from Argo recordings
- Default bag path is `~/argo/bags/argo_20251024_122903` if not specified
- Plot output is saved to `/tmp/gps_lora_track.png`
- All scripts handle missing data gracefully

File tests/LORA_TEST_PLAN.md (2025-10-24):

# LoRa Communication Test Plan

## Test Environment Setup

### Shore Side
1. Connect Waveshare USB-TO-LoRa module to laptop/PC
2. Verify serial port: `ls /dev/ttyACM*` or `ls /dev/ttyUSB*`
3. Source ROS2: `source /opt/ros/humble/setup.bash`
4. Start test monitor: `python3 shore/lora_test.py --port /dev/ttyACM0`

### Argo Side
1. Ensure LoRa module connected via SPI (pins 19,21,23,27,29,31)
2. SSH to Argo: `ssh orangepi@<ARGO_IP>`
3. Start test monitor: `python3 scripts/lora_test_argo.py`
4. Start LoRa node: `ros2 run argo lora.py` (or via lifecycle manager)

## Test Cases

### TEST 1: Basic Connectivity
**Objective**: Verify bidirectional LoRa communication

**Steps**:
1. Start shore test monitor
2. Start Argo LoRa node
3. Observe ping messages flowing shore→argo (every 5s)
4. Observe status packets flowing argo→shore (every 10s)

**Expected Results**:
- Shore logs show: "← PACKET" messages every 10 seconds
- Argo logs show: "← RX PACKET" and "PING" messages every 5 seconds
- No JSON parse errors
- Packet sizes < 100 bytes

### TEST 2: Packet Content Validation
**Objective**: Verify all critical fields present and formatted correctly

**Steps**:
1. Start Argo with GPS active
2. Monitor shore-side logs for 60 seconds
3. Verify packet contains: lat, lon, sog, cog, bat, hum, hdg, seq

**Expected Results**:
- All packets contain lat/lon with 6 decimal places
- SOG rounded to 2 decimals, COG to 1 decimal
- Battery voltage present and reasonable (6-9V range)
- Human control flag is boolean
- Sequence numbers increment properly

### TEST 3: Bandwidth Measurement
**Objective**: Measure actual bandwidth usage and air time

**Steps**:
1. Run for 5 minutes with standard 10s interval
2. Check shore test monitor statistics
3. Calculate: (avg_packet_size * 8) / avg_interval = bps

**Expected Results**:
- Average packet size: 80-100 bytes
- Average interval: 10 seconds
- Estimated bandwidth: 64-80 bps
- Well under SF7 limit (~1000 bps at 1km)

### TEST 4: Ping Timeout Detection
**Objective**: Verify Argo detects shore connection loss

**Steps**:
1. Start both sides, verify communication
2. Stop shore-side test monitor
3. Wait 35 seconds
4. Check Argo logs for timeout warning

**Expected Results**:
- After ~30 seconds: "Shore ping timeout" warning
- lora_connection_status topic publishes False
- If RTH enabled: "Triggering RETURN TO HOME" message

### TEST 5: Return-to-Home Command
**Objective**: Test RTH command transmission and reception

**Steps**:
1. Start both sides
2. From shore monitor, send: `{"cmd":"return_home"}`
3. Monitor Argo logs and controller behavior

**Expected Results**:
- Argo logs: "← COMMAND: return_home"
- Controller logs: "RETURN TO HOME activated"
- Boat state: return_to_home_active = True

### TEST 6: Dual-Source Dashboard
**Objective**: Verify dashboard shows correct data source

**Steps**:
1. Start Argo with both WiFi and LoRa active
2. Open web dashboard
3. Verify data source indicator shows "WiFi"
4. Disable WiFi connection
5. Wait 5 seconds
6. Verify data source switches to "LoRa"

**Expected Results**:
- Dashboard initially shows "WiFi" source
- After WiFi loss, switches to "LoRa" within 5 seconds
- Data continues updating via LoRa topics
- Age indicators show data freshness

### TEST 7: Signal Strength Monitoring
**Objective**: Test RSSI reporting at various distances

**Steps**:
1. Start at 10m distance, record RSSI
2. Move to 50m, 100m, 500m, 1km
3. Log RSSI at each distance

**Expected Results**:
- RSSI degrades with distance
- Communication maintained at 1km (RSSI > -120 dBm)
- Packet loss < 10% at maximum range

## Log Analysis

### Shore Log Format
```
[2025-01-15 10:30:45.123] → PING #42 sent (23 bytes)

[2025-01-15 10:30:47.456] ← PACKET #21 (87 bytes): {"ts":1234567890,...}

[2025-01-15 10:30:47.457]   └─ GPS: 37.123456, -122.234567 | SOG: 3.2 kt | ...
```

### Argo Log Format
```
[2025-01-15 10:30:45.124] ← RX PACKET #42: {"cmd":"ping","seq":42}

[2025-01-15 10:30:45.125]   └─ PING #42 (interval: 5.01s)

[2025-01-15 10:30:45.126]   └─ RSSI: -85 dBm
```

## Success Criteria

- ✓ Bidirectional communication established
- ✓ Packet loss < 5% at 100m, < 10% at 1km
- ✓ All critical fields present in packets
- ✓ Bandwidth usage < 100 bps average
- ✓ Ping timeout detected within 35 seconds
- ✓ RTH command successfully triggers controller
- ✓ Dashboard seamlessly switches between WiFi and LoRa

## Troubleshooting

### No packets received on shore
- Check serial port connection: `ls -l /dev/ttyACM*`
- Verify baud rate matches (115200)
- Check LoRa frequency matches both sides (433MHz)

### No pings received on Argo
- Verify LoRa node is running: `ros2 node list | grep lora`
- Check SPI connections and GPIO pins
- Monitor raw LoRa RX: `ros2 topic echo /lora_rx_data`

### High packet loss
- Check RSSI levels (< -110 dBm is marginal)
- Reduce distance or increase TX power
- Check for interference on 433MHz band

## Testing Strategy

1. **Unit Testing**: Individual component testing with test scripts
2. **Integration Testing**: Full system test with dual monitors running
3. **Range Testing**: Distance measurements with RSSI logging
4. **Bandwidth Validation**: Verify packet sizes and air time estimates
5. **Failover Testing**: WiFi disconnect scenarios with dashboard monitoring
6. **Duration Testing**: 24-hour continuous operation with periodic log analysis
7. **Stress Testing**: Rapid command transmission to test bandwidth limits

## Configuration Parameters

### nodes/lora.py
- `tx_interval_sec`: 10.0 (adjust based on bandwidth testing)
- `rth_on_ping_loss`: false (enable for production, disable for development)
- `ping_timeout_sec`: 30.0

### shore/lora_shore.py
- `ping_interval_sec`: 5.0
- `reconnect_interval`: 1.0

## Files Modified

1. `nodes/lora.py` - Add GPS position, ping reception, RTH logic, bandwidth monitoring
2. `shore/lora_shore.py` - Parse abbreviated keys, add GPS publishers, implement ping transmission
3. `nodes/argo_web_dashboard.py` - Dual-source subscriptions, data age tracking, source indication
4. `nodes/controller.py` - Already has LoRa command handling, no changes needed

## Expected Packet Format

**Argo to Shore** (every 10 seconds):

```json
{"ts":1234567890,"seq":42,"lat":37.123456,"lon":-122.123456,"sog":3.2,"cog":45.5,"bat":12.6,"hum":false,"hdg":47.3}
```

Size: ~90 bytes (fits within budget)

**Shore to Argo** (every 5 seconds):

```json
{"cmd":"ping","seq":123}
```

Size: ~25 bytes

**Shore to Argo** (RTH command):

```json
{"cmd":"return_home"}
```

Size: ~21 bytes

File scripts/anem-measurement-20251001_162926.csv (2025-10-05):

angle_deg | wind_speed_ref | sample_count | dp_ctr_mean | dp_ctr_std | dp_cw_mean | dp_cw_std | dp_ccw_mean | dp_ccw_std | temp_mean
-180 | 7.4 | 48 | -40.11276041666667 | 5.8298932940915265 | -2.4862847222222224 | 1.7375233058516657 | -4.686458333333333 | 2.3762381793157776 | 31.769131944444446
-135 | 7.4 | 48 | -9.31657986111111 | 6.264265172332147 | 4.686197916666667 | 5.165145746421688 | -41.14409722222222 | 5.5165550662001195 | 31.37104166666667
-90 | 7.4 | 48 | -2.305295138888889 | 2.1325147524129293 | 18.06171875 | 3.239631191171377 | -38.22855902777778 | 5.84373731118543 | 31.01961805555556
-45 | 7.4 | 48 | -1.4152777777777779 | 1.6916870494575729 | 32.52204861111111 | 6.001123120091611 | -21.400781249999998 | 3.582904191059325 | 30.731979166666672
0 | 7.4 | 48 | 36.22682291666667 | 6.386685057675317 | 2.123263888888889 | 2.6939080087784744 | 1.4673611111111111 | 2.1139636019429253 | 30.57607638888889
45 | 7.4 | 48 | 26.360069444444445 | 4.496085523617932 | -2.259635416666667 | 1.9884195542380425 | 25.31345486111111 | 4.78754459167653 | 30.573541666666667
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

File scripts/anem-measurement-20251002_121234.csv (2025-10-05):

angle_deg | wind_speed_ref | sample_count | dp_ctr_mean | dp_ctr_std | dp_cw_mean | dp_cw_std | dp_ccw_mean | dp_ccw_std | temp_mean
-180 | 7.4 | 96 | -43.74609375 | 5.714094214283337 | -8.158333333333333 | 2.682597609305032 | 2.393489583333333 | 2.1694679917823967 | 30.599895833333335
-150 | 7.4 | 96 | -22.160112847222223 | 3.168581848713916 | -30.21258680555556 | 4.749504762924604 | -0.06106770833333333 | 2.012432947263762 | 29.478107638888886
-120 | 7.4 | 96 | -0.4534722222222222 | 2.0151467874670024 | -34.36219618055555 | 4.480995921886627 | 6.630729166666666 | 2.1566008210649055 | 29.074427083333333
-90 | 7.4 | 96 | -1.1445746527777778 | 2.123128611553666 | -26.72508680555556 | 4.317936931824059 | 19.474565972222223 | 8.14530063793458 | 28.90571180555556
-60 | 7.4 | 96 | 1.0810329861111112 | 1.8904139641354987 | -4.159505208333333 | 1.9627365081380552 | 32.509114583333336 | 3.623483694310694 | 28.891527777777778
-30 | 7.4 | 96 | 26.330859375 | 4.119877596823191 | 1.1018229166666667 | 1.881967168704414 | 18.317621527777778 | 3.2799095850758855 | 28.897395833333334
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

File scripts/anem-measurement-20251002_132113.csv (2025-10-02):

angle_deg | wind_speed_ref | sample_count | dp_ctr_mean | dp_ctr_std | dp_cw_mean | dp_cw_std | dp_ccw_mean | dp_ccw_std | temp_mean
-180 | 7.4 | 67 | -26.323009950248757 | 5.17858691306355 | -3.6392412935323386 | 3.273131512645693 | 2.361380597014926 | 1.9315836865074558 | 28.789950248756217
-150 | 7.4 | 67 | -18.908893034825873 | 3.057212106169177 | -27.73507462686567 | 4.5398295013757775 | -1.2625621890547265 | 1.9949923695568945 | 28.19512437810945
-120 | 7.4 | 67 | -4.096517412935324 | 1.8874132486701638 | -28.18264925373134 | 4.190087879894535 | 3.910572139303483 | 2.3959841860747537 | 28.027014925373138
-90 | 7.4 | 67 | -0.5211442786069651 | 2.181176338693691 | -17.448694029850742 | 3.897097043356438 | 20.491915422885576 | 3.9753500346912034 | 28.102064676616912
-60 | 7.4 | 67 | 1.0661691542288556 | 1.8689126616545384 | -2.7641791044776123 | 1.2922916277574503 | 32.05876865671642 | 4.4035213496600045 | 28.238084577114424
-30 | 7.4 | 67 | 20.94850746268657 | 4.0818479315150835 | -0.5177238805970148 | 2.1776737182167136 | 14.796828358208954 | 2.80457392361301 | 28.370870646766168
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

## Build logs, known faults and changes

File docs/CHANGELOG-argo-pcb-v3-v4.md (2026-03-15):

# Argo PCB v3 -> v4 Changelog

This changelog summarizes the important hardware/software updates required when moving from Argo PCB v3 to v4.

## Scope

- Orange Pi Zero 2W 40-pin header mappings
- I2C bus topology and runtime adapter mapping
- Power-control LED and button behavior
- Node-level pin and bus updates
- Boot overlay and installation flow

## Hardware Mapping Changes

- **Power button (`POW_BUT`) moved**:
  - from older mapping to `PH0` (pin 8, GPIO line 224).
- **LoRa chip select (`!LORA_SEL`) moved**:
  - now uses line `264` (header pin 3 / `SDA.1`).
- **Blue LED path changed**:
  - `PI1` is no longer the direct blue LED control path (testpoint role).
  - Blue LED state is tied to charger signaling (`!CHG` / `PC12`) behavior.
- **Green heartbeat LED remains on PH4**:
  - PH4 drives both power-button green LED and HB LED path.
- **`PG` (pin 38) clarified**:
  - from CH221K USB-C PD logic, currently unused by software.

## I2C Topology Changes (Critical)

- Wind/mast bus on v4 is on **TWI2** (pins 27/28).
- Linux adapter numbering for TWI2 is **not fixed** across images/DT ordering.
  - observed as `i2c-3` or `i2c-4`.
- `i2c-2` may be HDMI DDC and should not be assumed to be wind/mast bus.

### Practical rule

- Resolve TWI2 at runtime from sysfs:
  - `/sys/devices/platform/soc*/5002800.i2c/i2c-*`

## Software Updates Applied

- `nodes/anem.py`
  - switched from hardcoded I2C bus to runtime TWI2 resolver.
- `nodes/argo_mast_leds.py`
  - switched from hardcoded I2C bus to runtime TWI2 resolver.
- `scripts/ai2c.sh`
  - now resolves TWI2 dynamically (aligned with `anem.py`).
- `nodes/gps.py`
  - added `!GPS_RESET` handling for prolonged failures.
  - added `GPS_PPS` status topic publication.
- `nodes/lora.py`
  - updated `!LORA_SEL` line to v4 mapping.
- `power_control/argo_power_control.py`
  - updated power button line.
  - robust green LED sysfs handling for both labels:
    - `/sys/class/leds/argo:green:heartbeat`
    - `/sys/class/leds/green_led`

## Boot/Overlay Integration Changes

- `power_control/orangepiEnv.txt`
  - updated overlays for v4 I2C path:
    - includes `pi-i2c0` and `pi-i2c2`.
- `power_control/Makefile`
  - `install` now includes:
    - `install-orangpienv` (copies authoritative `power_control/orangepiEnv.txt` to `/boot`)
    - `install-sys-heartbeat` (installs PH4 heartbeat overlay + permissions service)
- `power_control/sys_heartbeat/Makefile`
  - `install` adds `argo-ph4-led-overlay` into `user_overlays` via centralized `manage_overlays.sh`.

## Documentation Added/Updated

- Added consolidated hardware reference:
  - `docs/README-pins-i2c.md`
- Updated:
  - `docs/README-i2c.md`
  - `docs/README-mast-leds.md`
  - `nodes/README.md`
  - `power_control/README.md`
  - `power_control/sys_heartbeat/README.md`

## Known Gotchas

- If `argo-ph4-led-overlay` is missing from `user_overlays`, LED label/behavior can differ from expected Argo path.
- If `argo-ph4-led-perms.service` fails, userspace LED control may fail with permission errors.
- If wind bus appears missing, first confirm resolved TWI2 Linux adapter before scanning.

## Quick Verification After Install/Reboot

```bash
# Boot overlay state
sudo sed -n '/^overlays=/p;/^user_overlays=/p' /boot/orangepiEnv.txt

# I2C adapters
i2cdetect -l
ls /sys/devices/platform/soc*/5002800.i2c/i2c-*

# Argo combined I2C check
ai2c

# Green LED label and control path
ls /sys/class/leds
for p in /sys/class/leds/argo:green:heartbeat /sys/class/leds/green_led; do [ -d "$p" ] && echo "$p"; done

# Power-control and permissions service status
sudo systemctl status argo_power_control.service --no-pager
sudo systemctl status argo-ph4-led-perms.service --no-pager
```

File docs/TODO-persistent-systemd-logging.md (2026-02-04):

# TODO: Persistent Systemd Logging (Simplify Argo Services)

This document captures analysis and recommendations for **simplifying all Argo systemd services** by making **all** systemd journal logging go to persistent SD storage globally, instead of per-service tee pipelines.

## Current Situation

Argo services are complicated by the need during development to have **persistent logging** so logs can be inspected across reboots. On Armbian/Orange Pi:

- **ramlog** often keeps `/var/log` (and thus `/var/log/journal`) in **zram/RAM**, so journal data is lost on reboot.
- Argo uses **`/var/log.hdd/persistent/`** as the canonical persistent log directory.

To get service output onto persistent storage, **each** Argo service currently:

1. Uses a **tee pipeline** in `ExecStart`, e.g.:
   ```bash
   exec /usr/bin/python3 /path/to/script.py |& tee -a /var/log.hdd/persistent/argo-*.log
   ```
2. Often adds `ExecStartPre=/bin/mkdir -p /var/log.hdd/persistent`.
3. Keeps `StandardOutput=journal` and `StandardError=journal` so output also goes to the journal (which may be volatile).

**Problems with this approach:**

- Every service has a **complicated** `ExecStart` (bash, pipe, tee, log path).
- The **pipe can block** if tee doesn’t read (e.g. full pipe buffer), making the process appear hung and producing no log output.
- Duplication: output is written both to the journal and to a file; maintenance and debugging are harder.

**Services that currently use this tee pattern** (as of this doc):

- `argo_power_control.service`
- `argo_battery_water.service`
- `argo_bno085.service`
- `argo_launch_standard.service`
- `argo_health_monitor.service`
- `argo_radio_servo_module.service`
- Plus some system-monitoring services (e.g. `orangepi-monitor.service`, `crash-dump.service`, `persistent-dmesg.service`) that write directly to `/var/log.hdd/persistent/` in other ways.

## Recommended Approach: Global Persistent Journal

**Idea:** Configure **systemd journald** so that its storage lives on **persistent SD** (e.g. under `/var/log.hdd/persistent` or equivalent). Then:

- All service stdout/stderr that goes to the journal (via `StandardOutput=journal` / `StandardError=journal`) is **automatically** on persistent storage and survives reboot.
- Argo services can **drop** the tee pipeline and `ExecStartPre=mkdir`; `ExecStart` becomes a simple command.
- One global configuration replaces per-service complexity.

### Why This Works

1. **Journal is the single sink:** Service output is captured by systemd and written by journald. If journald’s storage is on disk (SD), all that output is persistent.
2. **No per-service tee:** No pipe, no tee, no per-service log file path—just a normal `ExecStart=... /path/to/script.py`.
3. **Existing tooling still works:** `alog` (argo_logs.sh) already uses **journalctl** to tail and grep by unit name; it does **not** read the tee’d files. So `alog` and `alog <pattern>` continue to work unchanged once everything is in the journal.
4. **Inspect after reboot:** `journalctl -u argo_power_control.service -b -1` (previous boot) and similar commands show persistent history as long as the journal is on disk.

## How to Put the Journal on Persistent Storage

Journald does **not** support an arbitrary path in its config. It uses a fixed layout under **`/var/log/journal`** when `Storage=persistent` (or `auto` with that directory present). So we don’t change the path in journald; we make **`/var/log/journal`** point at our persistent location.

### Option: Bind-mount journal to SD

1. **Create directory on persistent mount**
   - e.g. `/var/log.hdd/persistent/journal` (reuse the same mount that already provides `/var/log.hdd/persistent`).

2. **Ensure the persistent mount is available early**
   - The unit that mounts `/var/log.hdd/persistent` (or the partition that contains it) must run before journald starts (or before any service that needs persistent journal). Ordering may require a mount unit and `Before=systemd-journald.service` (or equivalent) as needed.

3. **Bind-mount over `/var/log/journal`**
   - In a mount unit (e.g. `var-log-journal.mount`) or in `/etc/fstab`:
   - Bind-mount: **`/var/log.hdd/persistent/journal`** → **`/var/log/journal`**
   - So journald still “sees” `/var/log/journal`, but the real data lives on SD.

4. **Configure journald for persistent storage**
   - In `/etc/systemd/journald.conf` (or a drop-in under `/etc/systemd/journald.conf.d/`):
   - Set **`Storage=persistent`**.
   - Restart journald after the bind mount and this config are in place.

5. **Ordering**
   - Mount that provides `/var/log.hdd/persistent`  
   - → then mount unit that bind-mounts `.../persistent/journal` to `/var/log/journal`  
   - → then `systemd-journald.service` (and all Argo services).

After this, **all** systemd logging (including every Argo service) goes into the journal, and the journal lives on SD. No tee needed.

## Simplifying Argo Services

Once the journal is on persistent storage as above:

**Remove from each Argo service:**

- `ExecStartPre=/bin/mkdir -p /var/log.hdd/persistent`
- The entire `|& tee -a /var/log.hdd/persistent/argo-*.log` pipeline

**Keep (or rely on default):**

- `StandardOutput=journal`
- `StandardError=journal`

**Set `ExecStart` to the simple command**, e.g.:

```ini
ExecStart=/bin/bash -c 'source /opt/ros/humble/setup.bash && exec /usr/bin/python3 /path/to/script.py'
```

(No pipe, no tee.)

## Trade-offs

- **Slower:** Writing to SD is slower than writing to zram; journal I/O may add a small delay under heavy logging.
- **SD wear:** More writes to the SD card. Acceptable for development; for long-term deployment, consider log size limits and rotation (journald has `SystemMaxUse`, `MaxFileSec`, etc.).
- **Single point of configuration:** One bind-mount and one journald config; if the mount fails, journal falls back to volatile storage unless additional safeguards are added.

## Summary

- **Problem:** Per-service tee to `/var/log.hdd/persistent` makes ExecStart complex and can cause pipe-blocking “hang” behavior.
- **Recommendation:** Put the **journal** on persistent SD (bind-mount `/var/log.hdd/persistent/journal` to `/var/log/journal`, set `Storage=persistent`), then **simplify all Argo services** by removing tee and mkdir from ExecStart.
- **Result:** One global configuration for persistent systemd logging; `alog` and journalctl continue to work; logs survive reboot; services stay simple and robust.

## Related

- **Current persistent logging:** `docs/README-persistent-logging.md` (ramlog, `/var/log.hdd/persistent`, Argo’s current setup).
- **Log viewer:** `scripts/argo_logs.sh` (alias `alog`) uses journalctl only; no change needed after moving to global persistent journal.

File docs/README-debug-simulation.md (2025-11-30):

# Debugging Argo Simulation Nodes

This guide explains how to debug simulation nodes (including the lifecycle manager and helper modules such as `mock_sailboat_simulator.py`) using the new debug-friendly launch flow.

---

## Prerequisites

- `debugpy` installed in the Python environment that runs Argo nodes:
  ```bash
  pip install debugpy
  ```
- Cursor / VS Code configured with the project’s `.vscode/launch.json`.
- ROS 2 Humble environment available under `/opt/ros/humble`.

> **Heads-up:** Cursor’s integrated terminal currently triggers a debug launcher timeout ([debugpy#1677](https://github.com/microsoft/debugpy/issues/1677), [Cursor forum report](https://forum.cursor.com/t/cursor-ide-cant-launch-debugpy-debugging-configurations/137001)). The `asimmock` launch configuration therefore uses `internalConsole` and relies on attach debugging for node processes.

---

## 1. Launch the Simulation Manager with Debug Flags

1. Open the `Run and Debug` panel.
2. Choose **`asimmock`**.
3. Press **Run**.

This configuration executes:

```bash
python3 launch/argo_lifecycle_manager.py \
  simulate_local \
  --debug-nodes \
  --debug-node-port-base 5680 \
  --debug-node-wait
```

Note: Mock simulation is now the default. Use `--real` to use the real simulator instead.

### What the flags do

- `--debug-nodes`: wraps each Python node (`argo_unified_simulator_bridge.py`, etc.) with `debugpy`.
- `--debug-node-port-base`: first debug port (`5680` by default); each subsequent node increments the port.
- `--debug-node-wait`: pauses each node at startup until a debugger is attached.

While nodes start, the lifecycle manager prints lines similar to:

```
🐞 argo_unified_simulator_bridge.py waiting for debugger attach on 127.0.0.1:5680
```

Make note of the port for the node you want to inspect.

---

## 2. Attach to a Node Process

1. In the `Run and Debug` panel, choose **`Python: Attach to Argo Node`**.
2. Edit the config’s port if necessary (default is `5680`).
3. Press **Run**.

Once attached, the debugger stops immediately (because `--debug-node-wait` holds the process) and loads breakpoints for files such as `nodes/mock_sailboat_simulator.py`. Press **Continue** to let execution flow.

> Tip: Add additional attach configurations if you routinely target multiple nodes simultaneously (e.g., ports `5681`, `5682`, …).

---

## 3. Working with Breakpoints

- Set breakpoints directly in the node source file (e.g., `mock_sailboat_simulator.py`).
- When the simulation hits the breakpoint (for example inside `MockSailboatSimulator.step()`), inspect variables via the standard debugger UI.
- If execution already passed the line before you attached, press **Continue** to wait for the next invocation, or trigger the relevant behavior at runtime.

---

## 4. Troubleshooting

| Symptom | Action |
| --- | --- |
| `Timed out waiting for launcher to connect` dialog | Ensure you launched **`asimmock`** (manager) with `internalConsole` and attach using the dedicated configuration. |
| No `🐞` lines in console | Confirm you passed `--debug-nodes` and `--debug-node-wait` to the lifecycle manager. |
| Attach fails with “connection refused” | Port mismatch—check the console for the actual port or verify that the node is still waiting. |
| Breakpoints grey (unbound) | Ensure the attach session is active and the source path matches (`/home/tobi/argo`). |

---

## 5. Exiting Cleanly

1. Stop the attach debugger session(s).
2. Terminate the `asimmock` launch in the Run and Debug panel.
3. Confirm the lifecycle manager prints `✅ Lifecycle manager shutdown complete - exiting`.

You can now restart the workflow or switch back to normal (non-debug) launches.

---

Happy debugging! Let the team know if additional scenarios should be covered in this guide.

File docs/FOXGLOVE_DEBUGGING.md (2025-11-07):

# Foxglove Studio Debugging Guide

## Viewing Detailed Error Messages in Foxglove Studio (Windows 11)

**Note**: Foxglove Studio may not provide easily accessible detailed logs. The best approach is to diagnose issues from the ROS2 side using command-line tools.

### Recommended: Use ROS2 Diagnostic Tools

Instead of trying to find Foxglove logs, diagnose issues using ROS2 commands:

#### Quick Diagnosis Script
```bash
# Run the diagnostic script
./scripts/diagnose_topic_schema.sh
```

This will show:
- Current topic types and any conflicts
- All publishers and subscribers
- Specific schema mismatch details

#### Manual Diagnosis
```bash
# Check topic types
ros2 topic info /rudder_sail_radio --verbose

# Check what nodes are publishing
ros2 node info /foxglove_bridge

# Check topic type
ros2 topic type /rudder_sail_radio

# Echo topic to see actual messages
ros2 topic echo /rudder_sail_radio
```

### Alternative: Browser Developer Tools (Web Version)

If using Foxglove Studio Web (browser version):
1. Press `F12` to open Developer Tools
2. Check Console tab for errors
3. Check Network tab for websocket issues

### Desktop App: Limited Logging Options

The Foxglove Studio desktop app does not expose detailed logs easily. The schema conflict errors are usually visible in:
- The main error message in the UI (often limited details)
- ROS2 topic diagnostics (recommended approach above)

## Common Schema Conflicts

### Error: "multiple channels advertise the same topic but the schema, name, or encoding do not match"

This happens when multiple publishers use different message types for the same topic.

### Diagnosing Schema Conflicts

**When simulation is running**, use the diagnostic script:

```bash
./scripts/diagnose_topic_schema.sh
```

This will show exactly what's wrong:
- Which nodes are publishing
- What message types they're using
- Specific conflicts

### Solution for `/rudder_sail_radio` Topic

The `/rudder_sail_radio` topic expects `geometry_msgs/msg/Vector3`.

**The Problem:**
- `foxglove_bridge` may be advertising it will publish `Twist` messages (from a misconfigured panel)
- The simulator bridge subscribes to `Vector3` messages
- This creates a schema conflict

**Solution: Use Joystick Panel Instead**

1. **Don't use Teleop panel** for `/rudder_sail_radio` - it causes conflicts
2. **Use Joystick panel** - publish to `/joy` topic instead
3. The simulator bridge automatically converts `/joy` to control commands

**If you must use `/rudder_sail_radio`:**

1. In Foxglove Studio, check all panels that might publish:
   - Remove or disable any Teleop panels
   - Remove or disable any panels publishing to `/rudder_sail_radio`
   - Ensure only Vector3 type is used
2. Configure Teleop panel (if using):
   - Set **Topic** to: `/rudder_sail_radio`
   - Set **Message Type** to: `geometry_msgs/msg/Vector3` (NOT Twist)
   - Configure mappings:
     - **X-axis** (rudder): `x` field (-1 to +1)
     - **Y-axis** (sail): `y` field (-1 to +1)
     - **Z-axis**: Leave as `z` field (should be 0.0)

**Alternative: Check Current Topic Types**
```bash
# On the ROS2 system (Linux/WSL)
ros2 topic info /rudder_sail_radio --verbose
```

This will show all publishers and subscribers with their message types.

## Verifying Topic Schema

### Check Topic Type
```bash
ros2 topic type /rudder_sail_radio
# Should output: geometry_msgs/msg/Vector3
```

### Check All Publishers
```bash
ros2 topic info /rudder_sail_radio --verbose
# Look for Publisher entries and their Topic type
```

### Test Publishing Correct Type
```bash
ros2 topic pub /rudder_sail_radio geometry_msgs/msg/Vector3 "{x: 0.5, y: -0.3, z: 0.0}"
```

### Echo Topic to Verify
```bash
ros2 topic echo /rudder_sail_radio
# Should show Vector3 messages with x, y, z fields
```

## Debugging Steps

1. **Check active publishers:**
   ```bash
   ros2 topic info /rudder_sail_radio --verbose
   ```

2. **Verify simulator bridge is subscribing:**
   ```bash
   ros2 node info /argo_unified_simulator_bridge | grep -A 5 "Subscribers"
   ```

3. **Check if foxglove_bridge is publishing incorrectly:**
   - The foxglove_bridge shouldn't publish to topics
   - It only forwards messages between ROS2 and websocket
   - If it's publishing, there may be a configuration issue

4. **Restart nodes:**
   ```bash
   # Stop simulation
   aq
   
   # Start simulation
   asim
   ```

5. **Check Foxglove connection:**
   - Verify websocket URL: `ws://localhost:8765`
   - Check connection status in Foxglove
   - Look for connection errors in Developer Console

## Expected Topic Configuration

For `/rudder_sail_radio`:
- **Type**: `geometry_msgs/msg/Vector3`
- **Fields**: 
  - `x` (float64): Rudder position (-1.0 to +1.0)
  - `y` (float64): Sail position (-1.0 to +1.0)
  - `z` (float64): Reserved (should be 0.0)
- **Publisher**: Foxglove Teleop panel (or terminal command)
- **Subscriber**: `argo_unified_simulator_bridge`

## Troubleshooting

### Issue: Foxglove shows Twist instead of Vector3
**Solution**: Configure Teleop panel to use Vector3 message type, not Twist.

### Issue: Multiple publishers with different types
**Solution**: Ensure all tools publishing to the topic use the same message type.

### Issue: Topic not appearing in Foxglove
**Solution**: 
1. Verify topic exists: `ros2 topic list | grep rudder_sail_radio`
2. Check foxglove_bridge is running: `ros2 node list | grep foxglove`
3. Restart foxglove_bridge if needed

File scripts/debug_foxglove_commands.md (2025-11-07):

# Debug Commands for Foxglove Connection from Remote Host

## Quick Test Commands (run on tobidh87)

### 1. Test Basic Connectivity
```bash
# Ping the router
ping -c 3 sensors-tobi-router.lan.ini.uzh.ch

# Check DNS resolution
host sensors-tobi-router.lan.ini.uzh.ch
nslookup sensors-tobi-router.lan.ini.uzh.ch
```

### 2. Test Port Connectivity
```bash
# Using netcat (nc)
nc -zv sensors-tobi-router.lan.ini.uzh.ch 8765

# Using telnet
telnet sensors-tobi-router.lan.ini.uzh.ch 8765
# (Press Ctrl+] then type 'quit' to exit)

# Using curl (HTTP test - will show if port is open)
curl -v --connect-timeout 5 http://sensors-tobi-router.lan.ini.uzh.ch:8765
```

### 3. Test WebSocket Connection
```bash
# Install wscat if needed
npm install -g wscat

# Test WebSocket connection
wscat -c ws://sensors-tobi-router.lan.uzh.ch:8765

# Or using curl to test WebSocket handshake
curl -v --no-buffer \
  -H "Connection: Upgrade" \
  -H "Upgrade: websocket" \
  -H "Sec-WebSocket-Version: 13" \
  -H "Sec-WebSocket-Key: $(openssl rand -base64 16)" \
  http://sensors-tobi-router.lan.ini.uzh.ch:8765
```

### 4. Test with Python (if available)
```python
import websocket
import ssl

try:
    ws = websocket.create_connection("ws://sensors-tobi-router.lan.ini.uzh.ch:8765", timeout=5)
    print("✅ WebSocket connection successful!")
    ws.close()
except Exception as e:
    print(f"❌ Connection failed: {e}")
```

### 5. Network Path Tracing
```bash
# Trace route to router
traceroute sensors-tobi-router.lan.ini.uzh.ch

# Check if port is reachable through firewall
# (if you have access to router)
```

## Expected Behavior

**Correct Setup:**
- Router: `sensors-tobi-router.lan.ini.uzh.ch:8765` 
- Forwards to: `10.0.0.3:8765` (Argo's foxglove_bridge)
- Argo's foxglove_bridge listens on: `0.0.0.0:8765` (all interfaces)

**Connection Flow:**
```
tobidh87 → sensors-tobi-router.lan.ini.uzh.ch:8765 
         → Router NAT/Port Forward 
         → 10.0.0.3:8765 
         → foxglove_bridge
```

## Common Issues

1. **Port not accessible**: Router firewall or port forwarding misconfigured
2. **DNS resolution fails**: Check if router hostname resolves correctly
3. **Connection timeout**: Router not forwarding correctly, or Argo's foxglove_bridge not running
4. **WebSocket handshake fails**: Protocol mismatch or firewall blocking WebSocket upgrade

## Verify on Argo Side

Run these on Argo (10.0.0.3) to verify foxglove_bridge is ready:

```bash
# Check if foxglove_bridge is running
ps aux | grep foxglove_bridge | grep -v grep

# Check if port is listening
netstat -tlnp | grep 8765
# or
ss -tlnp | grep 8765

# Check ROS2 node
ros2 node list | grep foxglove
```

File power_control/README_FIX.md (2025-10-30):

# Critical Battery Monitoring Fix - Complete Guide

## 🚨 Critical Safety Fix Implemented

**Date**: October 9, 2025  
**Priority**: CRITICAL - Deploy before next sea trial  
**Status**: ✅ Fix implemented and tested

---

## 📋 Quick Summary

### The Bug
Last night, battery dropped to 6V but Argo didn't halt. The critical battery confirmation dialog timed out, which **cancelled the halt** instead of proceeding with it. System kept running at critical voltage.

### The Fix
Inverted dialog return logic:
- **Timeout → Halt PROCEEDS** (safe default for autonomous operation)
- **User clicks Cancel → Halt cancelled** (allows developer intervention)

### Additional Improvements
- ✅ Service startup dependencies fixed
- ✅ 60-second grace period for startup
- ✅ Charging status logging added
- ✅ Consecutive failure tracking added
- ✅ Test mode works without gpiod

---

## 📂 Documentation

| File | Purpose |
|---|---|
| **`DEPLOYMENT_SUMMARY.md`** | Quick deployment guide - START HERE |
| **`FIX_SUMMARY.md`** | Complete technical details of all fixes |
| **`CRITICAL_BUG_REPORT.md`** | Original bug analysis |
| **`SERVICE_DEPENDENCY_FIX.md`** | Service ordering fix details |
| **`FINAL_TEST.md`** | Final verification testing guide |
| **`QUICK_TEST_GUIDE.md`** | Quick testing instructions |
| **`TESTING_GUIDE.md`** | Detailed testing procedures |
| **`README_FIX.md`** | This file - overview of everything |

---

## 🧪 Test Scripts

| Script | Purpose |
|---|---|
| **`test_fix_verification.sh`** | Verify dialog timeout fix |
| **`test_service_startup.sh`** | Test 60s grace period |
| **`test_battery_scenarios.sh`** | Comprehensive battery tests |
| **`setup_ros2_env.sh`** | ROS2 environment setup (auto-deactivates conda) |
| **`run_mock_battery.sh`** | Run mock battery service (for split terminal) |
| **`run_power_control_test.sh`** | Run power control test (for split terminal) |
| **`mock_battery_service.py`** | Mock battery service with charging simulation |

---

## ⚡ Quick Test (2 Minutes)

Verify the main fix works:

**Terminal 1:**
```bash
cd /home/tobi/Dropbox/GitHub/SensorsINI/argo
source power_control/setup_ros2_env.sh
python3 power_control/mock_battery_service.py --voltage 6.0 --charging --ac-power
```

**Terminal 2:**
```bash
cd /home/tobi/Dropbox/GitHub/SensorsINI/argo
source power_control/setup_ros2_env.sh
python3 power_control/argo_power_control.py --test-mode
```

**Watch Terminal 2 for**:
- ✅ `Battery voltage check: 6.000V, AC Power: YES, Charging: ACTIVE`
- ✅ `CRITICAL BATTERY DETECTED: 6.000V < 7.2V, AC Power: YES, Charging: ACTIVE`
- ✅ `Showing confirmation dialog - timeout (no action) will proceed with halt`

**Dialog behavior**:
- Let it timeout (30s) → Should see: "proceeding with halt (safe default)"
- Click "Cancel" → Should see: "CANCELLED by user intervention"

---

## 🚀 Deploy to Argo

### Step 1: Copy Files
```bash
# From development machine
scp power_control/argo_power_control.py orangepi@argo:~/argo/power_control/
scp power_control/argo_power_control.service orangepi@argo:~/argo/power_control/
```

### Step 2: Update Systemd
```bash
# On Argo
sudo systemctl stop argo_power_control.service
sudo cp ~/argo/power_control/argo_power_control.service /etc/systemd/system/
sudo systemctl daemon-reload
sudo systemctl start argo_power_control.service
```

### Step 3: Verify
```bash
# Check startup
sudo journalctl -u argo_power_control.service -n 50 | grep "Battery service"
# Should see: "Battery service is now available - critical battery monitoring active"

# Check battery monitoring  
sudo journalctl -u argo_power_control.service -n 20 | grep "Battery voltage"
# Should see: Battery voltage checks every 30s with charging status
```

---

## 🎯 What's Fixed

| Issue | Before | After |
|---|---|---|
| Dialog timeout | ❌ Halt cancelled | ✅ Halt proceeds |
| Headless operation | ❌ No halt | ✅ Automatic halt |
| 6V + charging | ❌ Kept running | ✅ Halts automatically |
| Service startup order | ❌ Race condition | ✅ Dependency enforced |
| Service crashes | ❌ Silent failure | ✅ Halt after 3 failures (90s) |
| I2C failures | ❌ Readings ignored | ✅ Halt after 3 invalid (90s) |
| Charging info | ❌ Not logged | ✅ Logged every 30s |
| Developer control | ❌ No override | ✅ Can cancel if present |

---

## 🔧 Technical Changes

### Files Modified:
1. **`argo_power_control.py`** - Main fix (dialog logic, monitoring, logging)
2. **`argo_power_control.service`** - Service dependencies

### Key Code Changes:
- `show_critical_battery_confirmation_dialog()`: Fixed return values (inverted)
- `monitor_critical_battery()`: Added grace period, charging logs, failure tracking
- `initiate_critical_battery_halt()`: Updated messages and logic
- Conditional gpiod import: Optional for test mode, required for production

---

## ✅ Verification

The fix has been tested and verified:
- ✅ Dialog timeout → halt proceeds (not cancelled)
- ✅ Charging status logged correctly
- ✅ Service startup grace period works
- ✅ Safe for remote testing without GPIO
- ✅ Production mode requires gpiod

Test logs saved in: `/tmp/power_control_test_output.log`

---

## 📞 Support

If issues occur during deployment:
1. Check logs: `sudo journalctl -u argo_power_control.service -u argo_battery_water.service -n 100`
2. Verify both services running: `sudo systemctl status argo_power_control.service argo_battery_water.service`
3. Check battery service: `ros2 service call /battery_status std_srvs/srv/Trigger`
4. Rollback if needed (see DEPLOYMENT_SUMMARY.md)

---

## 🌊 Ready for Sea!

This fix makes the critical battery monitoring system **safe for autonomous operation**:
- ✅ No human interaction required
- ✅ Automatic halt on critical battery
- ✅ Preserves power for manual radio control
- ✅ Developer can still intervene if present

**Deploy before next sea trial!** 🚀

---

## Quick Reference

**Deploy**: See `DEPLOYMENT_SUMMARY.md`  
**Test**: See `FINAL_TEST.md` or `QUICK_TEST_GUIDE.md`  
**Details**: See `FIX_SUMMARY.md`  
**Bug Analysis**: See `CRITICAL_BUG_REPORT.md`  
**Service Order**: See `SERVICE_DEPENDENCY_FIX.md`

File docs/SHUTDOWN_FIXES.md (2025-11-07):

# ROS2 Shutdown Handling Fixes

## Problems Identified

From the terminal output, we saw several shutdown-related issues:

1. **"Failed to publish log message to rosout: publisher's context is invalid"** - Nodes trying to log after ROS2 context shutdown
2. **"rcl_shutdown already called on the given context"** - Multiple calls to `rclpy.shutdown()`
3. **Uncoordinated shutdown** - Signal handler calling `stop()` while continuous loop also handles shutdown

## Root Causes

### 1. Double rclpy.shutdown() Calls
The lifecycle manager's signal handler called `_cleanup_ros2()` which called `rclpy.shutdown()`, but then individual nodes also called `rclpy.shutdown()` in their own cleanup, causing the "rcl_shutdown already called" error.

### 2. Logging After Context Shutdown
When `rclpy.shutdown()` is called, it invalidates the ROS2 context. Nodes that try to publish log messages after this point get the "publisher's context is invalid" error.

### 3. Race Conditions
The signal handler immediately called `stop()` and `sys.exit()`, racing with the continuous monitoring loop's own shutdown handling.

## Fixes Applied

### 1. Added Shutdown Coordination Flag

```python
def __init__(self, quiet: bool = True):
    # ... existing code ...
    self.shutdown_requested = False  # Flag to coordinate shutdown
```

This flag allows all parts of the system to check if shutdown has been requested and avoid duplicate cleanup.

### 2. Improved Signal Handler

**Before:**
```python
def _signal_handler(self, signum, frame):
    print(f"\n🛑 argo_lifecycle_manager: Received signal {signum}, shutting down...")
    self._cleanup_ros2()  # BAD: Immediate cleanup
    self.stop()           # BAD: Races with main loop
    sys.exit(0)           # BAD: Abrupt exit
```

**After:**
```python
def _signal_handler(self, signum, frame):
    if self.shutdown_requested:
        return  # Already shutting down
    
    self.shutdown_requested = True
    print(f"\n🛑 argo_lifecycle_manager: Received signal {signum}, shutting down...")
    
    # Don't call stop() here - let the main loop handle it
    # Just set the flag and let continuous() exit cleanly
```

The signal handler now just sets a flag and lets the main loop handle the shutdown gracefully.

### 3. Protected ROS2 Cleanup

```python
def _cleanup_ros2(self):
    """Clean up ROS2 resources - only call this once at final shutdown"""
    if self.ros2_node:
        try:
            # Destroy node first
            self.ros2_node.destroy_node()
        except Exception:
            # Silently fail - context may already be shutdown
            pass
        self.ros2_node = None
    
    # Only shutdown context if it's still valid
    if ROS2_AVAILABLE and rclpy.ok():
        try:
            rclpy.shutdown()
        except Exception:
            # Silently fail - may already be shutdown
            pass
```

Now checks if `rclpy.ok()` before calling `shutdown()` to avoid double-shutdown errors.

### 4. Graceful Main Loop Exit

**Before:**
```python
while rclpy.ok() if self.ros2_node else True:
    rclpy.spin_once(self.ros2_node, timeout_sec=0.1)
    # ... monitoring code ...

except KeyboardInterrupt:
    self.stop()
    return True
```

**After:**
```python
while not self.shutdown_requested and (rclpy.ok() if self.ros2_node else True):
    if self.ros2_node:
        try:
            rclpy.spin_once(self.ros2_node, timeout_sec=0.1)
        except Exception:
            # Context may be shutting down
            if self.shutdown_requested:
                break
    # ... monitoring code ...

except KeyboardInterrupt:
    self.shutdown_requested = True
finally:
    # Publish final status before cleanup
    self._publish_status_update("Argo lifecycle manager stopping")
    
    # Stop all nodes first
    self.stop()
    
    # Clean up ROS2 last
    self._cleanup_ros2()
    
    return True  # Always return True for clean exit
```

Key improvements:
- Check `shutdown_requested` flag in loop condition
- Wrap `spin_once()` in try/except to handle context shutdown
- Use `finally` block to ensure cleanup always happens
- Stop nodes before cleaning up ROS2 context

### 5. Selective Cleanup in main()

```python
try:
    if args.command == 'run':
        # continuous() handles its own cleanup
        success = manager.continuous()
        sys.exit(0 if success else 1)
    elif args.command == 'stop':
        success = manager.stop()
        # Clean up ROS2 for non-continuous commands
        manager._cleanup_ros2()
        sys.exit(0 if success else 1)
    # ... other commands also call cleanup ...
except Exception as e:
    print(f"❌ Unexpected error: {e}")
    manager._cleanup_ros2()
    sys.exit(1)
```

Only `continuous()` and `simulate()` methods handle their own cleanup. Other commands call `_cleanup_ros2()` explicitly.

## Expected Behavior After Fixes

### Clean Shutdown Sequence

1. **Signal received** (SIGINT/SIGTERM)
2. **Flag set** (`shutdown_requested = True`)
3. **Main loop exits** (checks flag, breaks out of loop)
4. **Status published** ("Argo lifecycle manager stopping")
5. **Nodes stopped** (`self.stop()` - terminates processes)
6. **ROS2 cleaned up** (`self._cleanup_ros2()` - destroys node, shuts down context)
7. **Exit** (returns True, exits cleanly)

### No More Errors

- ✅ No "rcl_shutdown already called" errors
- ✅ No "publisher's context is invalid" errors
- ✅ No race conditions between signal handler and main loop
- ✅ Clean, orderly shutdown of all nodes

## Testing the Fixes

### Test 1: Normal Shutdown (Ctrl+C)
```bash
python3 launch/argo_lifecycle_manager.py run
# Wait for nodes to start
# Press Ctrl+C
# Should see clean shutdown without errors
```

### Test 2: Signal-Based Shutdown
```bash
python3 launch/argo_lifecycle_manager.py run &
PID=$!
sleep 10
kill -TERM $PID  # Send SIGTERM
# Should see clean shutdown
```

### Test 3: Service-Based Stop
```bash
# Terminal 1:
python3 launch/argo_lifecycle_manager.py run

# Terminal 2:
ros2 service call /argo/lifecycle/stop std_srvs/srv/Trigger
# Should stop cleanly
```

## Node Shutdown Issues - FIXED

Individual nodes (like `argo_transform_publisher.py`, `sailing_area_publisher.py`, `argo_boat_visualization.py`) have been updated to follow the proper shutdown pattern and should no longer show "rcl_shutdown already called" errors.

### Recommended Node Pattern

Nodes should check if context is still valid before calling shutdown:

```python
def main():
    rclpy.init()
    node = MyNode()
    try:
        rclpy.spin(node)
    except KeyboardInterrupt:
        pass
    except rclpy.executors.ExternalShutdownException:
        pass  # Context already shutdown
    finally:
        node.destroy_node()
        # Only shutdown if context is still valid
        if rclpy.ok():
            try:
                rclpy.shutdown()
            except:
                pass  # Already shutdown
```

This pattern has been applied to the following nodes:
- ✅ `argo_transform_publisher.py` - Updated with proper shutdown handling
- ✅ `sailing_area_publisher.py` - Updated with proper shutdown handling  
- ✅ `argo_boat_visualization.py` - Updated with proper shutdown handling

Other ROS2 nodes in the system should follow this same pattern if they show shutdown errors.

## Benefits

1. **Clean Logs** - No more confusing error messages during shutdown
2. **Reliable** - Shutdown always completes successfully
3. **Coordinated** - All parts of system agree on shutdown state
4. **Debuggable** - Clear, predictable shutdown sequence
5. **Robust** - Handles edge cases (double signals, quick Ctrl+C, etc.)

To start the system, use the `al` alias, which is configured to run `sudo systemctl start argo_launch_standard.service`.
```bash
al
```

Check the status with the `as` alias.
```bash
as
```

To stop the system, use `aq`.
```bash
aq
```

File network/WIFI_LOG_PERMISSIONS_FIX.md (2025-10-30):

# WiFi Reconnection Log Permission Fix

## Problem

When the systemd service rotates log files in `/var/log.hdd/persistent`, the new `wifi-reconnect.log` file was created with root ownership. Since the service was running as user `orangepi`, it couldn't append to the log file, resulting in "Permission denied" errors.

### Root Cause

1. **Log Rotation**: When journald or other system processes rotate logs, they create new files as root
2. **Service User**: The service was running as `User=orangepi`, which couldn't write to root-owned files
3. **Permission Denied**: The `tee -a` command in the script failed when trying to append to a root-owned file

## Solution

The fix involves two changes:

### 1. Service Configuration (`network/config/argo_wifi_reconnect.service`)

Changed the service to run as root instead of orangepi:

```ini
[Service]
Type=oneshot
User=root
Group=root
ExecStart=~/argo/network/scripts/wifi_reconnect.sh
Environment="HOME=/home/orangepi"
Environment="USER=orangepi"
```

**Why root?**
- Root can always write to log files, even after rotation
- Root can fix file permissions if needed
- NetworkManager operations (nmcli) work regardless of user when run by root
- Log files are owned by root with 644 permissions (readable by all)

### 2. Script Permissions Handler (`network/scripts/wifi_reconnect.sh`)

Added `ensure_log_permissions()` function that:

1. Creates the log directory if needed
2. Creates the log file with correct permissions (644 - readable by all)
3. Ensures the file is readable after rotation

```bash
ensure_log_permissions() {
    mkdir -p "$(dirname "$LOG_FILE")"
    
    if [ ! -f "$LOG_FILE" ]; then
        touch "$LOG_FILE"
        chmod 644 "$LOG_FILE"
        # Service runs as root, log file is owned by root
    else
        # Ensure file is readable by all
        chmod 644 "$LOG_FILE" 2>/dev/null || true
    fi
}
```

The `log_message()` function now calls `ensure_log_permissions()` before every write, ensuring the file always has correct permissions.

## Benefits

1. **Automatic Recovery**: Handles log rotation gracefully without manual intervention
2. **Consistent Permissions**: Log files are always readable by all users (644 permissions)
3. **No Permission Errors**: Root can always write to log files, even after rotation
4. **User-Friendly**: Log files are readable by any user for monitoring

## Testing

To test the fix:

```bash
# Manually rotate the log to simulate the issue
sudo mv /var/log.hdd/persistent/wifi-reconnect.log /var/log.hdd/persistent/wifi-reconnect.log.old
sudo touch /var/log.hdd/persistent/wifi-reconnect.log

# Verify it's owned by root
ls -la /var/log.hdd/persistent/wifi-reconnect.log
# Should show root:root with 644 permissions

# Run the script (or wait for timer to trigger)
systemctl start argo_wifi_reconnect.service

# Verify permissions
ls -la /var/log.hdd/persistent/wifi-reconnect.log
# Should show root:root with 644 permissions (readable by all)

# Check logs for successful writes
tail -f /var/log.hdd/persistent/wifi-reconnect.log
```

## Installation

After making these changes, the service must be reinstalled using the top-level Makefile:

```bash
# Reinstall the WiFi reconnection system (this will install the updated service and script)
make install-network-improvements

# Or if the service is already running, just reload and restart
sudo systemctl daemon-reload
sudo systemctl restart argo_wifi_reconnect.timer

# Verify it's running
systemctl status argo_wifi_reconnect.service
```

## Alternative Solutions Considered

1. **Run as orangepi with sudo in script**: Would require password or sudoers configuration
2. **ACL permissions**: More complex, harder to maintain
3. **Separation of concerns**: Separate log rotation from the service
4. **Change rotation tool**: Would require changing system-wide configuration

The chosen solution is simple, maintainable, and robust.

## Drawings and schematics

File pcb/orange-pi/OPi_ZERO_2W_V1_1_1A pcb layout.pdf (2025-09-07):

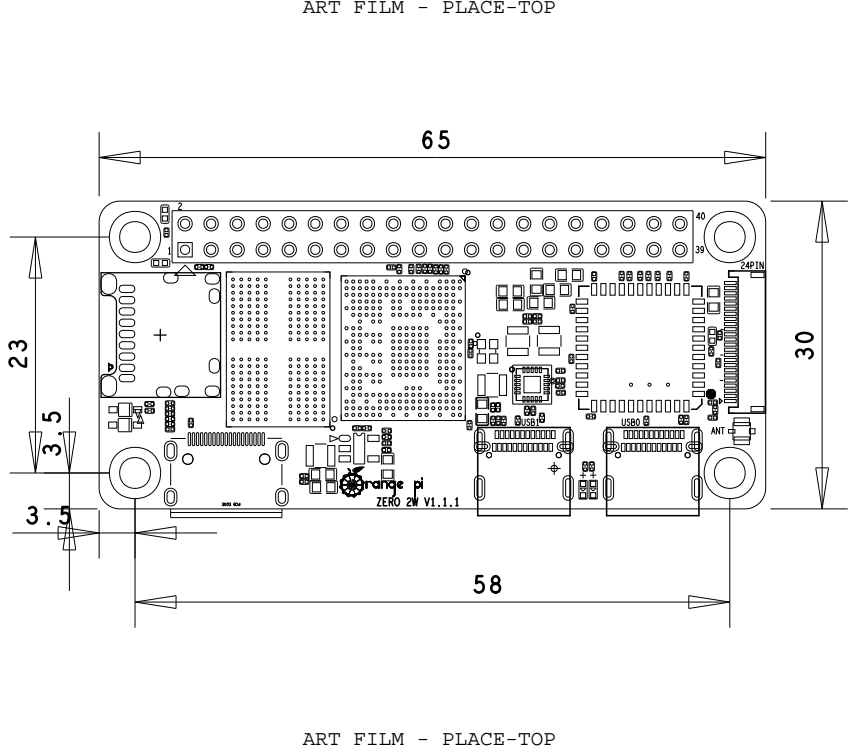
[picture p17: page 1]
24PIN; ANT; USB1; USB0

ART FILM - PLACE-TOP

ZERO 2W V1.1.1 PCB EDGE

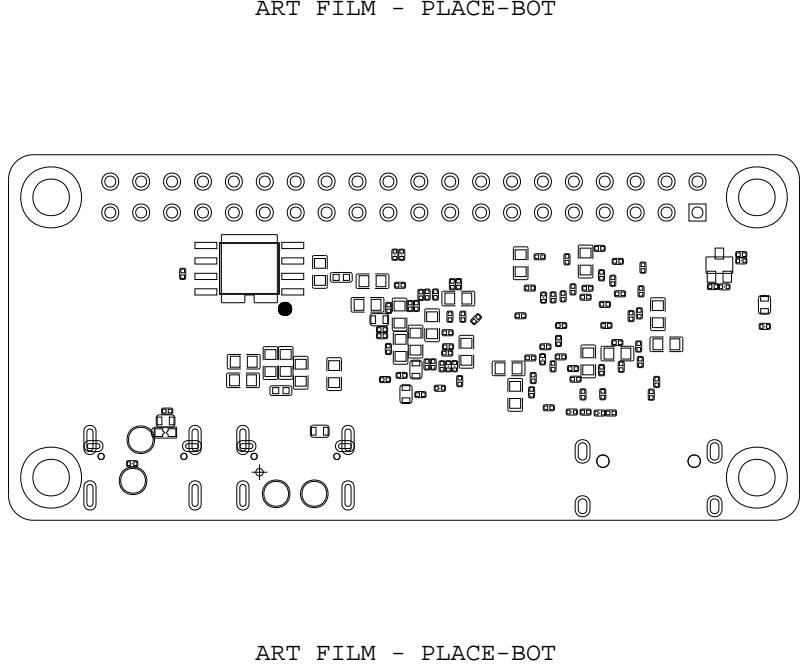
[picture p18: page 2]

ART FILM - PLACE-BOT

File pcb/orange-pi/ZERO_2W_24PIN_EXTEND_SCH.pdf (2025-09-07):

# 24 PIN CONNECTOR

# Foxconn UB1112C-8FDH-4F

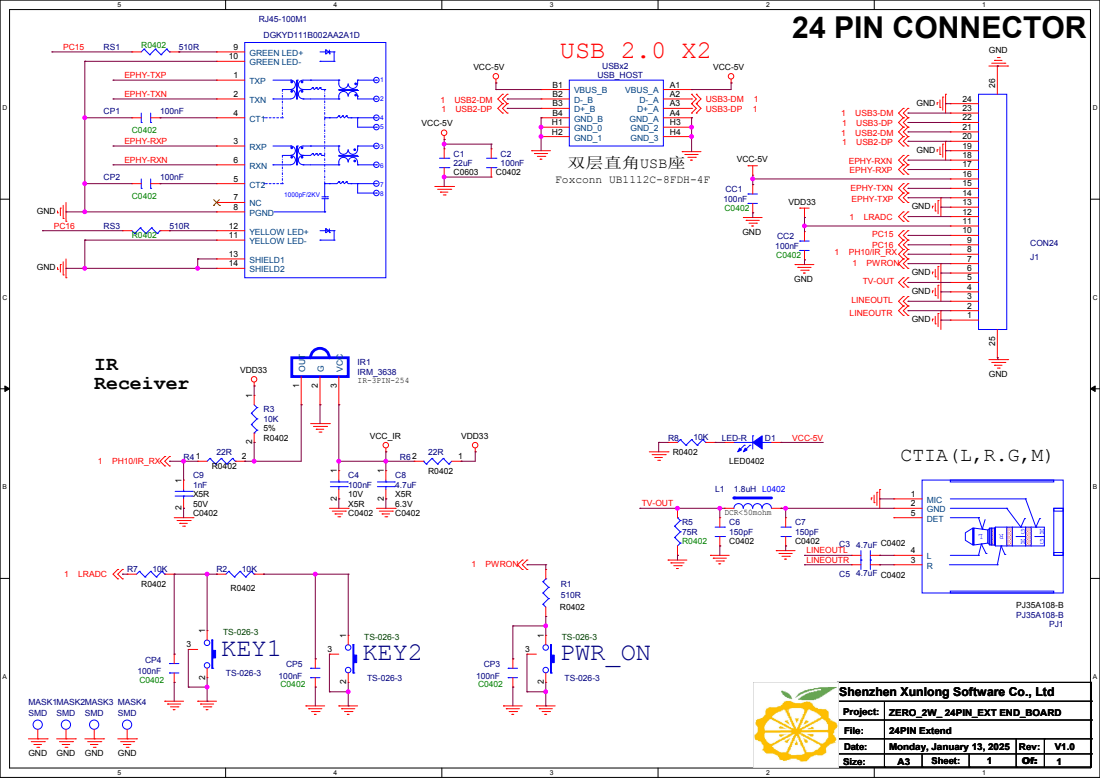
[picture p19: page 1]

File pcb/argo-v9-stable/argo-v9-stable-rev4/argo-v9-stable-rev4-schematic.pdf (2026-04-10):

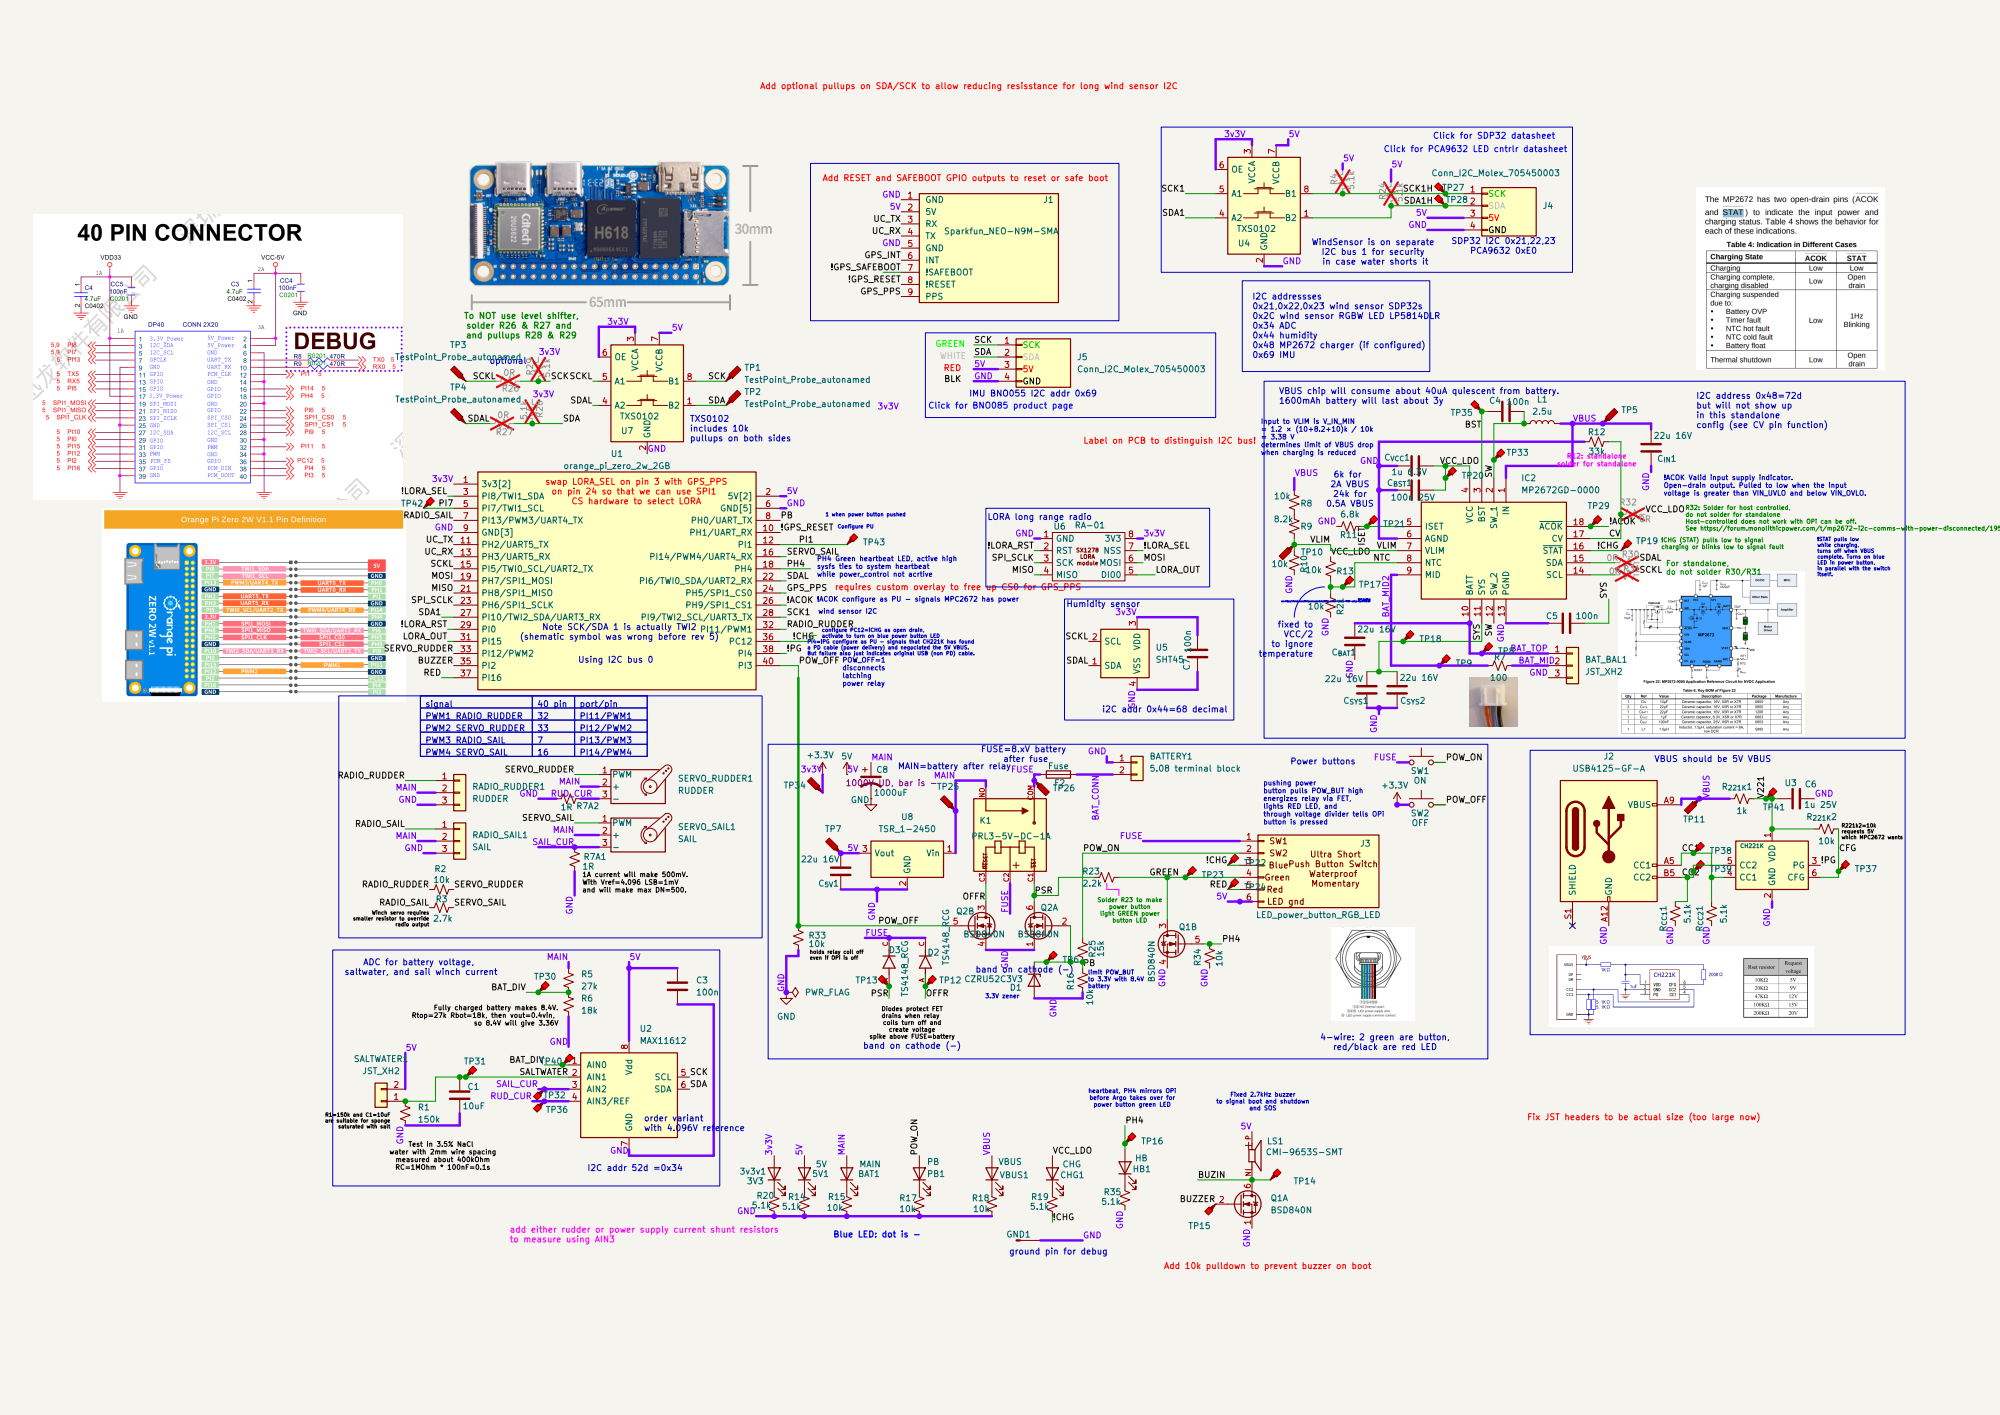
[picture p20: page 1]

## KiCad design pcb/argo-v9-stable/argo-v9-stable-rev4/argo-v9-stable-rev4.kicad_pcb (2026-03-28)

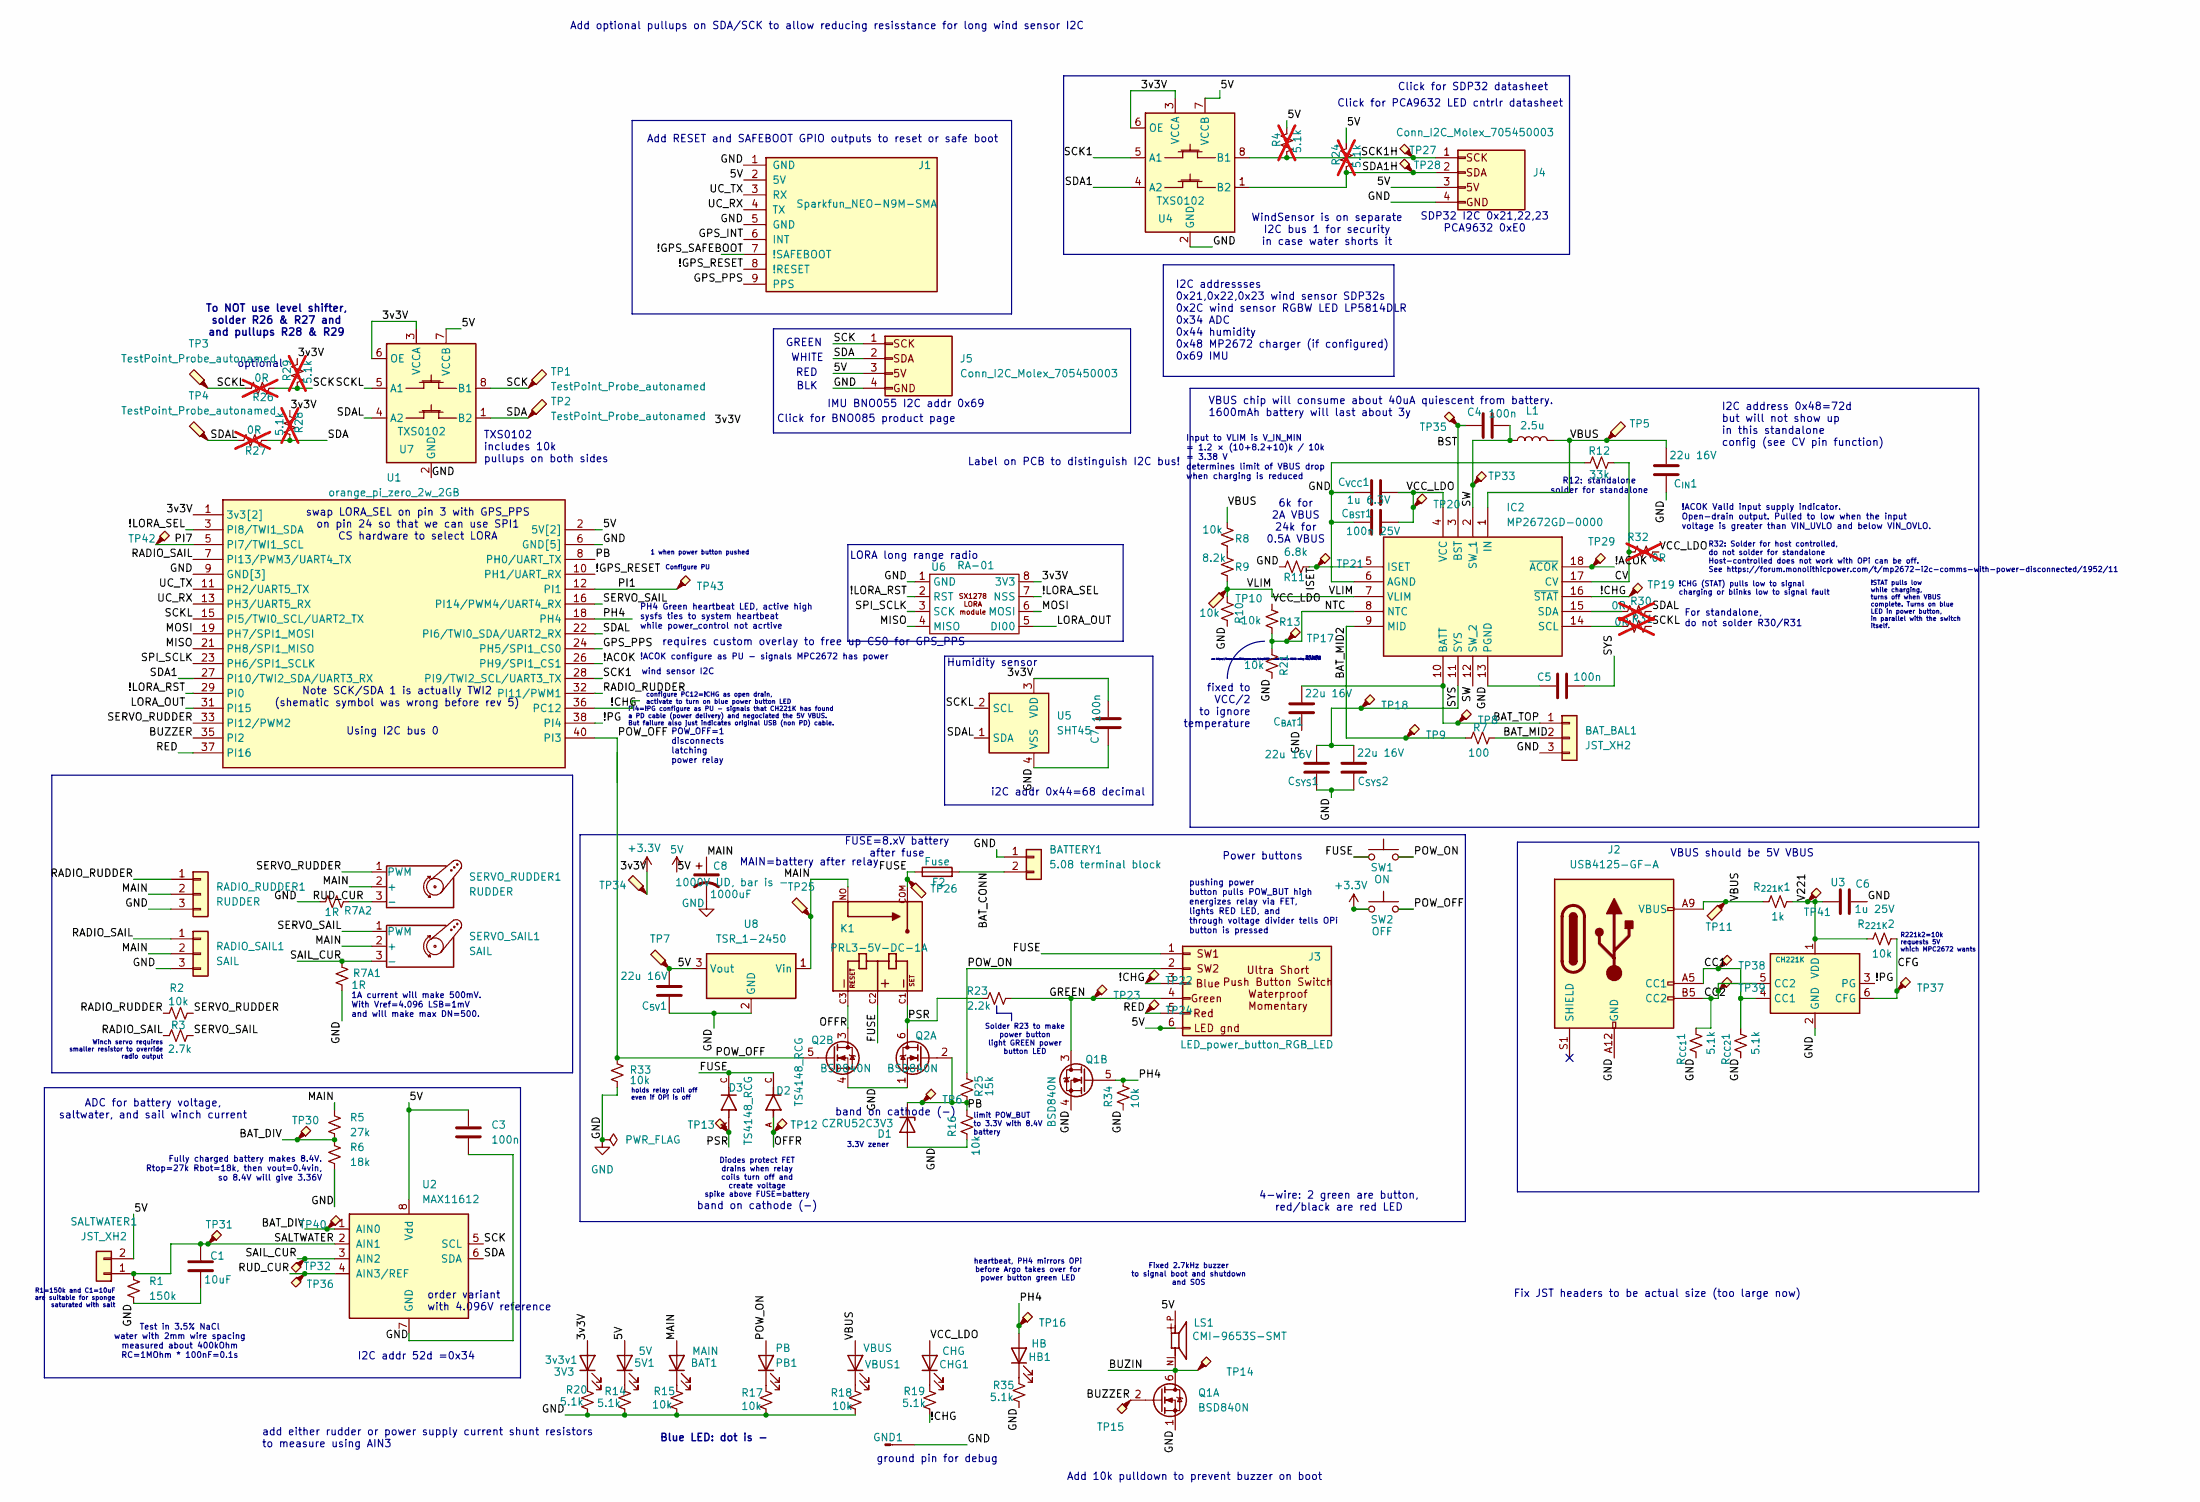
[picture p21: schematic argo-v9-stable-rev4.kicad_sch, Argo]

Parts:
3v3v1: 3V3; LED_0603_1608Metric_Pad1.05x0.95mm_HandSolder
5V1: 5V; LED_0603_1608Metric_Pad1.05x0.95mm_HandSolder
BAT1: MAIN; LED_0603_1608Metric_Pad1.05x0.95mm_HandSolder
BATTERY1: 5.08 terminal block; TerminalBlock_Phoenix_MKDS-1,5-2-5.08_1x02_P5.08mm_Horizont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
BAT_BAL1: JST_XH2; JST_XH_S3B-XH-A-1_1x03_P2.50mm_Horizontal
C1: 10uF; C_0603_1608Metric_Pad1.08x0.95mm_HandSolder
C3, C4, C5, C7: 100n; C_0603_1608Metric_Pad1.08x0.95mm_HandSolder
C6: 1u 25V; C_0603_1608Metric_Pad1.08x0.95mm_HandSolder
C8: 1000uF; PCAP_10x10-ELECT_NCA; digikey have 4 in lab
CHG1: CHG; LED_0603_1608Metric_Pad1.05x0.95mm_HandSolder
C_{5V}1: 22u 16V; C_1210_3225Metric_Pad1.33x2.70mm_HandSolder
C_{BAT}1: 22u 16V; C_1210_3225Metric_Pad1.33x2.70mm_HandSolder
C_{BST}1: 100n 25V; C_0603_1608Metric_Pad1.08x0.95mm_HandSolder
C_{IN}1: 22u 16V; C_1210_3225Metric_Pad1.33x2.70mm_HandSolder
C_{SYS}1, C_{SYS}2: 22u 16V; C_1210_3225Metric_Pad1.33x2.70mm_HandSolder
C_{VCC}1: 1u 6.3V; C_0603_1608Metric_Pad1.08x0.95mm_HandSolder
D1: CZRU52C3V3; D_0603_1608Metric_hand_solder
D2, D3: TS4148_RCG; DIO_TS4148_RCG; PARTREV A2301
F2: Fuse; Fuse_Smd- Nano SMF AliExp
GND1: Conn_01x01_Pin; Pin_D1.0mm_L10.0mm_LooseFit
HB1: HB; LED_0603_1608Metric_Pad1.05x0.95mm_HandSolder
IC2: MP2672GD-0000; QFN40P200X300X100-18N-D-handsolder; Manufacturer_Part_Number MP2672GD-0000
J1: Sparkfun_NEO-N9M-SMA; Sparkfun_NEO-M9N-SMA
J2: USB4125-GF-A; USB_C_Receptacle_GCT_USB4125-xx-x-0190_6P_TopMnt_Horizontal
J3: LED_power_button_RGB_LED; JST_XH_S6B-XH-A_1x06_P2.50mm_Horizontal
J4, J5: Conn_I2C_Molex_705450003; I2C_header
K1: PRL3-5V-DC-1A; RELAY_PRL3-5V-DC-1A; PARTREV 1.0
L1: 2.5u; L_Aliexpress_2.5uH
LS1: CMI-9653S-SMT; CUI_CMI-9653S-SMT
PB1: PB; LED_0603_1608Metric_Pad1.05x0.95mm_HandSolder
Q1, Q2: BSD840N; SOT-363_SC-70-6-handsolder
R1: 150k; R_0603_1608Metric_Pad0.98x0.95mm_HandSolder
R2, R8, R10, R13, R15, R16, R17, R18, R21, R33, R34: 10k; R_0603_1608Metric_Pad0.98x0.95mm_HandSolder
R3: 2.7k; R_0603_1608Metric_Pad0.98x0.95mm_HandSolder
R4, R24, R28, R29: 5.1k; R_0603_1608Metric_Pad0.98x0.95mm_HandSolder; not fitted
R5: 27k; R_0603_1608Metric_Pad0.98x0.95mm_HandSolder
R6: 18k; R_0603_1608Metric_Pad0.98x0.95mm_HandSolder
R7: 100; R_0603_1608Metric_Pad0.98x0.95mm_HandSolder
R7A1, R7A2: 1R; R_0603_1608Metric_Pad0.98x0.95mm_HandSolder
R9: 8.2k; R_0603_1608Metric_Pad0.98x0.95mm_HandSolder
R11: 6.8k; R_0603_1608Metric_Pad0.98x0.95mm_HandSolder
R12: 33k; R_0603_1608Metric_Pad0.98x0.95mm_HandSolder
R14, R19, R20, R35: 5.1k; R_0603_1608Metric_Pad0.98x0.95mm_HandSolder
R23: 2.2k; R_0603_1608Metric_Pad0.98x0.95mm_HandSolder
R25: 15k; R_0603_1608Metric_Pad0.98x0.95mm_HandSolder
R26, R27, R30, R31, R32: 0R; R_0603_1608Metric_Pad0.98x0.95mm_HandSolder; not fitted
RADIO_RUDDER1: RUDDER; PinHeader_1x03_P2.54mm_Vertical
RADIO_SAIL1: SAIL; PinHeader_1x03_P2.54mm_Vertical
R_{221K}1: 1k; R_0603_1608Metric_Pad0.98x0.95mm_HandSolder
R_{221K}2: 10k; R_0603_1608Metric_Pad0.98x0.95mm_HandSolder
R_{CC1}1, R_{CC2}1: 5.1k; R_0603_1608Metric_Pad0.98x0.95mm_HandSolder
SALTWATER1: JST_XH2; JST_XH_S2B-XH-A_1x02_P2.50mm_Horizontal
SERVO_RUDDER1: RUDDER; PinHeader_1x03_P2.54mm_Vertical
SERVO_SAIL1: SAIL; PinHeader_1x03_P2.54mm_Vertical
SW1: ON; SW_Tactile_SPST_NO_Straight_CK_PTS636Sx25SMTRLFS
SW2: OFF; SW_Tactile_SPST_NO_Straight_CK_PTS636Sx25SMTRLFS
TP1, TP2, TP3, TP4, TP5, TP7, TP10, TP11, TP25, TP26, TP34: TestPoint_Probe_autonamed; TestPoint_scope_probe_autonamed
TP6, TP8, TP9, TP12, TP13, TP14, TP15, TP16, TP17, TP18, TP19, TP20, TP21, TP22, TP23, TP24, TP27, TP28, TP29, TP30, TP31, TP32, TP33, TP35, TP36, TP37, TP38, TP39, TP40, TP41, TP42, TP43: TestPoint_Probe_autonamed; TestPoint_scope_small_autonamed
U1: orange_pi_zero_2w_2GB; orange_pi_zero_2w
U2: MAX11612; MSOP-8_3x3mm_P0.65mm
U3: CH221K; TSOT-23-6_HandSoldering
U4, U7: TXS0102; SSOP-8_2.95x2.8mm_P0.65mm
U5: SHT45; Sensirion_DFN-4_1.5x1.5mm_P0.8mm_SHT4x_NoCentralPad-handsol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
U6: RA-01; RA-01 SX1278 LORA
U8: TSR_1-2450; Converter_DCDC_TRACO_TSR1-xxxxE_THT
VBUS1: VBUS; LED_0603_1608Metric_Pad1.05x0.95mm_HandSolder

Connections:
5V: 5V1.2 (A), C3.1, C_{5V}1.2, J1.2 (5V), J3.6, J4.3 (5V), J5.3 (5V), LS1.P, R4.2, R24.2, SALTWATER1.2, TP7.1, U1.2 (5V[2]), U1.4 (5V[2]), U2.8 (Vdd), U4.7 (VCCB), U7.7 (VCCB), U8.3 (Vout)
+3.3V: 3v3v1.2 (A), C7.2, R28.2, R29.2, SW2.1, TP34.1, U1.1 (3v3[2]), U1.17 (3v3[2]), U4.3 (VCCA), U4.6 (OE), U5.3 (VDD), U6.8 (3V3), U7.3 (VCCA), U7.6 (OE)
/!ACOK: IC2.18 (~ACOK), TP29.1, U1.26 (PH9/SPI1_CS1)
/!CHG: IC2.16 (~STAT), J3.3, R19.2, TP19.1, TP22.1, U1.36 (PC12)
/!GPS_RESET: J1.8 (!RESET), U1.10 (PH1/UART_RX)
/!GPS_SAFEBOOT: J1.7 (!SAFEBOOT)
/!LORA_RST: U1.29 (PI0), U6.2 (RST)
/!LORA_SEL: U1.3 (PI8/TWI1_SDA), U6.7 (NSS)
/!PG: U1.38 (PI4), U3.3 (PG)
/BAT_CONN: BATTERY1.2, F2.2
/BAT_DIV: R5.2, R6.1, TP30.1, TP40.1, U2.1 (AIN0)
/BAT_MID: BAT_BAL1.2, R7.1
/BAT_MID2: IC2.9 (MID), R7.2, TP9.1
/BAT_TOP: BAT_BAL1.1, C_{BAT}1.2, IC2.10 (BATT), TP8.1
/BST: C4.1, IC2.3 (BST), TP35.1
/BUZIN: LS1.N, Q1.6 (D), TP14.1
/BUZZER: Q1.2 (G), TP15.1, U1.35 (PI2)
/CC1: J2.A5 (CC1), R_{CC2}1.2, TP38.1, U3.4 (CC1)
/CC2: J2.B5 (CC2), R_{CC1}1.2, TP39.1, U3.5 (CC2)
/CFG: R_{221K}2.2, TP37.1, U3.6 (CFG)
/CV: IC2.17 (CV), R12.1, R32.1
/FUSE: D2.C, D3.C, F2.1, J3.1, K1.C2, K1.COM, SW1.1, TP26.1
/GPS_INT: J1.6 (INT)
/GPS_PPS: J1.9 (PPS), U1.24 (PH5/SPI1_CS0)
/GREEN: J3.4, Q1.3 (D), R23.2, TP23.1
/ISET: IC2.5 (ISET), R11.2, TP21.1
/LORA_OUT: U1.31 (PI15), U6.5 (DI00)
/MAIN: BAT1.2 (A), C8.1, K1.NO, R5.1, RADIO_RUDDER1.2, RADIO_SAIL1.2, SERVO_RUDDER1.2 (+), SERVO_SAIL1.2 (+), TP25.1, U8.1 (Vin)
/MISO: U1.21 (PH8/SPI1_MISO), U6.4 (MISO)
/MOSI: U1.19 (PH7/SPI1_MOSI), U6.6 (MOSI)
/NTC: IC2.8 (NTC), R13.2, R21.1, TP17.1
/OFFR: D2.A, K1.C3, Q2.3 (D), TP12.1
/PB: D1.1 (K), Q2.2 (G), R16.2, R25.1, TP6.1, U1.8 (PH0/UART_TX)
/PH4: HB1.2 (A), Q1.5 (G), R34.2, TP16.1, U1.18 (PH4)
/PI1: TP43.1, U1.12 (PI1)
/PI7: TP42.1, U1.5 (PI7/TWI1_SCL)
/POW_OFF: Q2.5 (G), R33.1, SW2.2, U1.40 (PI3)
/POW_ON: J3.2, PB1.2 (A), R25.2, SW1.2
/PSR: D3.A, K1.C1, Q2.6 (D), R23.1, TP13.1
/RADIO_RUDDER: R2.1, RADIO_RUDDER1.1, U1.32 (PI11/PWM1)
/RADIO_SAIL: R3.1, RADIO_SAIL1.1, U1.7 (PI13/PWM3/UART4_TX)
/RED: J3.5, TP24.1, U1.37 (PI16)
/RUD_CUR: R7A2.1, SERVO_RUDDER1.3 (-), TP36.1, U2.4 (AIN3/REF)
/SAIL_CUR: R7A1.1, SERVO_SAIL1.3 (-), TP32.1, U2.3 (AIN2)
/SALTWATER: C1.1, R1.1, SALTWATER1.1, TP31.1, U2.2 (AIN1)
/SCK: J5.1 (SCLK), R26.2, R29.1, TP1.1, U2.5 (SCL), U7.8 (B1)
/SCK1: U1.28 (PI9/TWI1_SCL/UART3_TX), U4.5 (A1)
/SCK1H: J4.1 (SCLK), R4.1, TP27.1, U4.8 (B1)
/SCKL: R26.1, R31.2, TP3.1, U1.15 (PI5/TWI0_SCL/UART2_TX), U5.2 (SCL), U7.5 (A1)
/SDA: J5.2 (SDA), R27.2, R28.1, TP2.1, U2.6 (SDA), U7.1 (B2)
/SDA1: U1.27 (PI10/TWI1_SDA/UART3_RX), U4.4 (A2)
/SDA1H: J4.2 (SDA), R24.1, TP28.1, U4.1 (B2)
/SDAL: R27.1, R30.2, TP4.1, U1.22 (PI6/TWI0_SDA/UART2_RX), U5.1 (SDA), U7.4 (A2)
/SERVO_RUDDER: R2.2, SERVO_RUDDER1.1 (PWM), U1.33 (PI12/PWM2)
/SERVO_SAIL: R3.2, SERVO_SAIL1.1 (PWM), U1.16 (PI14/PWM4/UART4_RX)
/SPI_SCLK: U1.23 (PH6/SPI1_SCLK), U6.3 (SCK)
/SW: C4.2, IC2.2 (SW_1), IC2.12 (SW_2), L1.1, TP33.1
/SYS: C5.2, C_{SYS}1.2, C_{SYS}2.2, IC2.11 (SYS), TP18.1
/UC_RX: J1.4 (TX), U1.13 (PH3/UART5_RX)
/UC_TX: J1.3 (RX), U1.11 (PH2/UART5_TX)
/V221: C6.1, R_{221K}1.2, R_{221K}2.1, TP41.1, U3.1 (VDD)
/VBUS: C_{IN}1.2, IC2.1 (IN), J2.A9 (VBUS), J2.B9 (VBUS), L1.2, R8.1, R_{221K}1.1, TP5.1, TP11.1, VBUS1.2 (A)
/VCC_LDO: CHG1.2 (A), C_{BST}1.2, C_{VCC}1.2, IC2.4 (VCC), R13.1, R32.2, TP20.1
/VLIM: IC2.7 (VLIM), R9.2, R10.1, TP10.1
GND: BATTERY1.1, BAT_BAL1.3, C1.2, C3.2, C5.1, C6.2, C7.1, C8.2, C_{5V}1.1, C_{BAT}1.1, C_{BST}1.1, C_{IN}1.1, C_{SYS}1.1, C_{SYS}2.1, C_{VCC}1.1, D1.2 (A), GND1.1, IC2.6 (AGND), IC2.13 (PGND), J1.1 (GND), J1.5 (GND), J2.A12 (GND), J2.B12 (GND), J4.4 (GND), J5.4 (GND), Q1.1 (S), Q1.4 (S), Q2.1 (S), Q2.4 (S), R1.2, R6.2, R7A1.2, R7A2.2, R10.2, R11.1, R12.2, R14.2, R15.2, R16.1, R17.2, R18.2, R20.2, R21.2, R33.2, R34.1, R35.2, RADIO_RUDDER1.3, RADIO_SAIL1.3, R_{CC1}1.1, R_{CC2}1.1, U1.6 (GND[5]), U1.9 (GND[3]), U1.14 (GND[5]), U1.20 (GND[5]), U1.25 (GND[3]), U1.30 (GND[5]), U1.34 (GND[5]), U1.39 (GND[3]), U2.7 (GND), U3.2 (GND), U4.2 (GND), U5.4 (VSS), U6.1 (GND), U7.2 (GND), U8.2 (GND)
unnamed: 3v3v1.1 (K), R20.1
unnamed: 5V1.1 (K), R14.1
unnamed: BAT1.1 (K), R15.1
unnamed: CHG1.1 (K), R19.1
unnamed: HB1.1 (K), R35.1
unnamed: IC2.14 (SCL), R31.1
unnamed: IC2.15 (SDA), R30.1
unnamed: PB1.1 (K), R17.1
unnamed: R8.2, R9.1
unnamed: R18.1, VBUS1.1 (K)

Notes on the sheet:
optional
Click for SDP32 datasheet
ground pin for debug
Add RESET and SAFEBOOT GPIO outputs to reset or safe boot
requires custom overlay to free up CS0 for GPS_PPS
PI4=!PG configure as PU - signals that CH221K has found a PD cable (power delivery) and negociated the 5V VBUS. But failure also just indicates original USB (non PD) cable.
add either rudder or power supply current shunt resistors to measure using AIN3
FUSE=8.xV battery after fuse
6k for 2A VBUS 24k for 0.5A VBUS
TXS0102 includes 10k pullups on both sides
R221k2=10k requests 5V which MPC2672 wants
wind sensor I2C
To NOT use level shifter, solder R26 & R27 and and pullups R28 & R29
pushing power button pulls POW_BUT high energizes relay via FET, lights RED LED, and through voltage divider tells OPi button is pressed
1A current will make 500mV. With Vref=4.096 LSB=1mV and will make max DN=500.
Input to VLIM is V_IN_MIN = 1.2 × (10+8.2+10)k / 10k = 3.38 V determines limit of VBUS drop when charging is reduced
Note SCK/SDA 1 is actually TWI2 (shematic symbol was wrong before rev 5)
Fully charged battery makes 8.4V. Rtop=27k Rbot=18k, then vout=0.4vin, so 8.4V will give 3.36V
BLK
Solder R23 to make power button light GREEN power button LED
fixed to VCC/2 to ignore temperature
Click for BNO085 product page
Winch servo requires smaller resistor to override radio output
configure PC12=!CHG as open drain, activate to turn on blue power button LED
holds relay coil off even if OPi is off
I2C address 0x48=72d but will not show up in this standalone config (see CV pin function)
I2C addr 52d =0x34
Fix JST headers to be actual size (too large now)
IMU BNO055 I2C addr 0x69
i2C addr 0x44=68 decimal
!ACOK Valid input supply indicator. Open-drain output. Pulled to low when the input voltage is greater than VIN_UVLO and below VIN_OVLO.
MAIN=battery after relay
Label on PCB to distinguish I2C bus!
!ACOK configure as PU - signals MPC2672 has power
Fixed 2.7kHz buzzer to signal boot and shutdown and SOS
band on cathode (-)
Add 10k pulldown to prevent buzzer on boot
Power buttons
R32: Solder for host controlled, do not solder for standalone Host-controlled does not work with OPi can be off. See https://forum.monolithicpower.com/t/mp2672-i2c-comms-with-power-disconnected/1952/11
heartbeat, PH4 mirrors OPi before Argo takes over for power button green LED

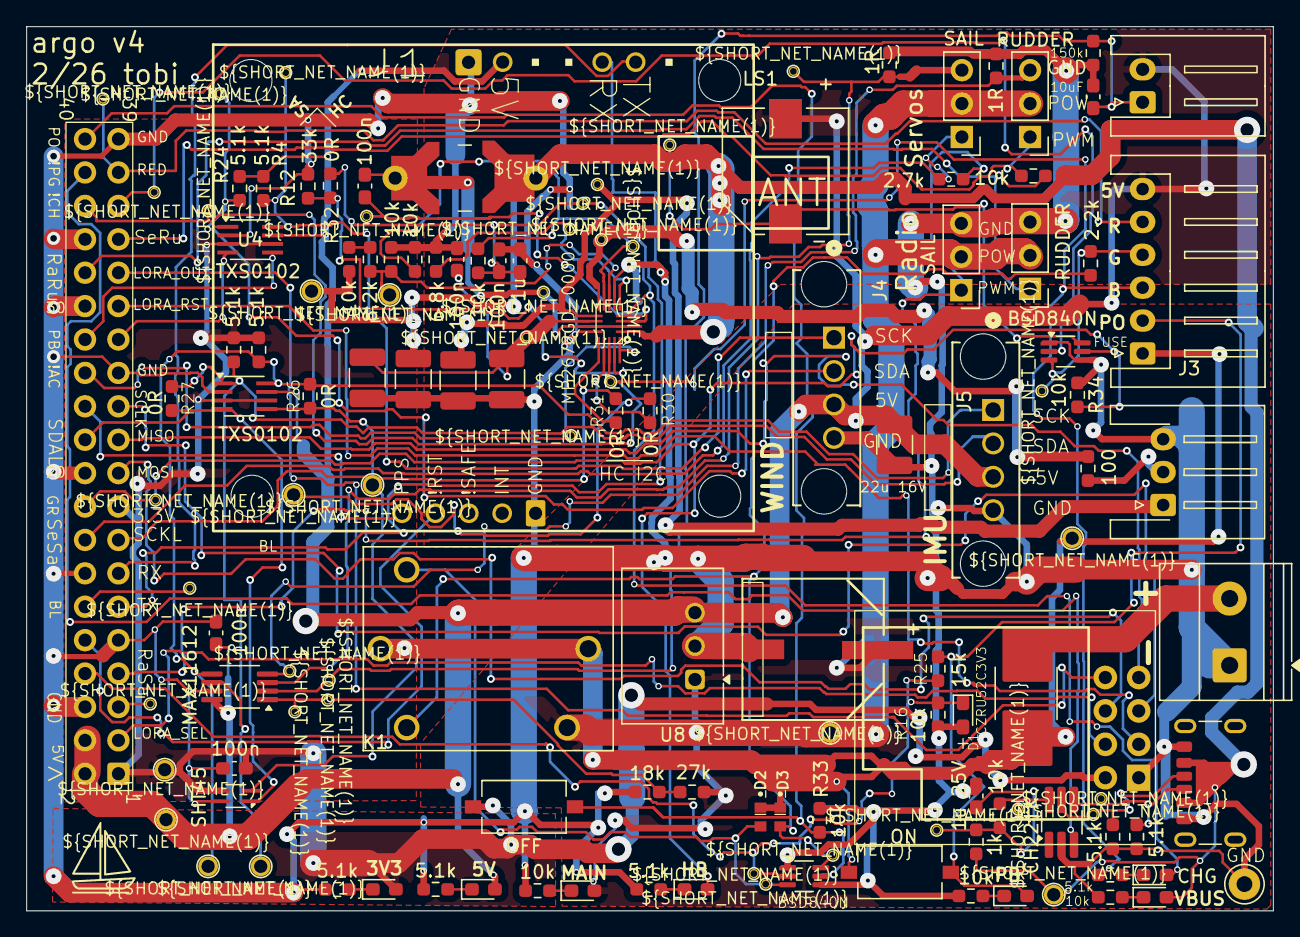
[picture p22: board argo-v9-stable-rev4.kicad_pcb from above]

Board: 2 copper layers, 94.8 x 67.2 mm, 137 parts (0 on the bottom side), 73 nets.

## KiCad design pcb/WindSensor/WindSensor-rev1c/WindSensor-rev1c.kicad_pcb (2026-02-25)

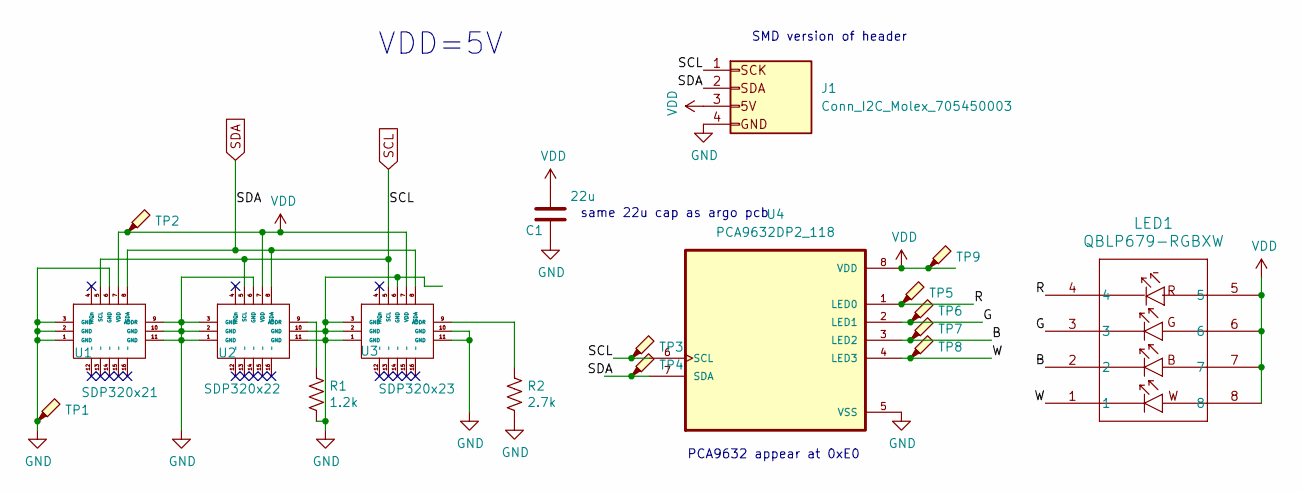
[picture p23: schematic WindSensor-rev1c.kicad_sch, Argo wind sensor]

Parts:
C1: 22u; C_1210_3225Metric_Pad1.33x2.70mm_HandSolder
J1: Conn_I2C_Molex_705450003; CONN_SD-74099-1000_04_MOL
LED1: QBLP679-RGBXW; LED_QBLP679E-RGBW
R1: 1.2k; R_0603_1608Metric_Pad0.98x0.95mm_HandSolder
R2: 2.7k; R_0603_1608Metric_Pad0.98x0.95mm_HandSolder
TP1, TP2, TP3, TP4: TestPoint_Probe_autonamed; TestPoint_scope_probe_autonamed
TP5, TP6, TP7, TP8, TP9: TestPoint_Probe_autonamed; TestPoint_scope_small_autonamed
U1: SDP320x21; SDP32
U2: SDP320x22; SDP32
U3: SDP320x23; SDP32
U4: PCA9632DP2_118; SOP65P490X110-8N; PARTREV 5

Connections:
/B: LED1.2, TP7.1, U4.3 (LED2)
/G: LED1.3, TP6.1, U4.2 (LED1)
/R: LED1.4, TP5.1, U4.1 (LED0)
/W: LED1.1, TP8.1, U4.4 (LED3)
GND: C1.1, J1.4 (GND), R1.2, R2.2, TP1.1, U1.1 (GND), U1.2 (GND), U1.3 (GND), U1.6 (GND), U1.9 (ADDR), U1.10 (GND), U1.11 (GND), U1.17 (GND), U1.18 (GND), U2.1 (GND), U2.2 (GND), U2.3 (GND), U2.6 (GND), U2.10 (GND), U2.11 (GND), U2.17 (GND), U2.18 (GND), U3.1 (GND), U3.2 (GND), U3.3 (GND), U3.6 (GND), U3.10 (GND), U3.11 (GND), U3.17 (GND), U3.18 (GND), U4.5 (VSS)
unnamed: R1.1, U2.9 (ADDR)
unnamed: R2.1, U3.9 (ADDR)
SCL: J1.1 (SCLK), TP3.1, U1.5 (SCL), U2.5 (SCL), U3.5 (SCL), U4.6 (SCL)
SDA: J1.2 (SDA), TP4.1, U1.8 (SDA), U2.8 (SDA), U3.8 (SDA), U4.7 (SDA)
VDD: C1.2, J1.3 (5V), LED1.5, LED1.6, LED1.7, LED1.8, TP2.1, TP9.1, U1.7 (VDD), U2.7 (VDD), U3.7 (VDD), U4.8 (VDD)

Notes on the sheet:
VDD=5V
same 22u cap as argo pcb
PCA9632 appear at 0xE0
SMD version of header

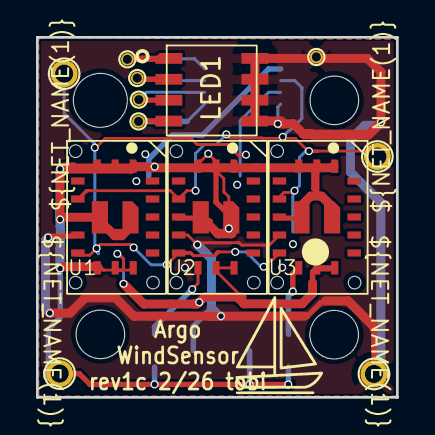
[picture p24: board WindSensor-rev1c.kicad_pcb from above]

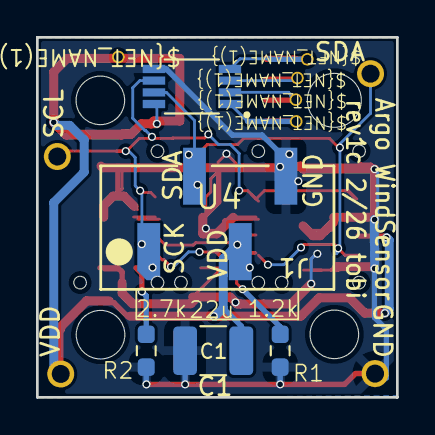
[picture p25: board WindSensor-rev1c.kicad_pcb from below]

Board: 2 copper layers, 20.0 x 20.0 mm, 22 parts (5 on the bottom side), 10 nets.

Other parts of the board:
H1, H2, H3, H4: (no value)

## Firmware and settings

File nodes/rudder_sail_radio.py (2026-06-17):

#!/usr/bin/env python3
# PYTHON_ARGCOMPLETE_OK
"""
ROS2 Rudder/Sail Control Node - Combined Hardware Interface and Control Arbitration

This node provides a unified interface for rudder/sail control, combining hardware
interaction with the argo_radio_servo_module kernel module and intelligent control
arbitration between human and autonomous control systems.

Hardware Interface:
- Uses argo_radio_servo_module kernel module for hardware PWM capture/generation
- Interfaces via sysfs at /sys/kernel/argo_radio_servo/
- Supports Orange Pi Zero 2W with custom GPIO/PWM configuration
- Real-time radio control input capture and normalization
- Safe servo output with pulse width validation (900-2100µs range)
- HIGH IMPEDANCE MODE: Writing 0 to servo control files disables PWM output,
  allowing radio control to pass through directly to servos via resistor network

Safety features:
- The radio channels are connected directly to the servo outputs by resistors. This way, if
  radio_sail_servo is not running, the PWM output pins are set to high impedance, so that the radio 
  directly drives the servo outputs. When radio_sail_servo is running, the radio inputs are passed through when
  the boat is human controlled. Under argo auto mode, the servos are controlled by controller.py.
- FAIL-SAFE DESIGN: Servo outputs start in high impedance mode (PWM disabled) for maximum safety
- HIGH IMPEDANCE MODE: Servos automatically switch to high impedance when not actively controlled

Control Arbitration:
- Intelligent human/robot control switching with human priority
- Automatic detection of human activity based on radio input changes
- Configurable timeout-based handover between control modes
- Safety limits and deadband filtering for robust operation
- High-frequency control loop (20Hz) for responsive arbitration

Key Features:
- Combined hardware interface and control logic in single node
- Default QoS for all topics (compatible with systemd and normal processes)
- Throttled logging to minimize system load
- Built-in safety features with high impedance defaults
- Graceful handling of hardware disconnection
- HIGH IMPEDANCE MODE: Automatic switching between PWM control and radio passthrough

Topics Published:
- /rudder_sail_radio: Vector3 with normalized radio inputs (-1 to +1)
  * x: rudder position (-1=full left, +1=full right, looking down at boat)
  * y: sail position (-1=pulled in fully, +1=let out fully)
  * z: reserved (currently 0)
  
- /rudder_sail_servo: Vector3 with actual servo commands being sent to hardware
  * Same format as radio topic but reflects actual servo positions
  
- /human_controlled: Bool indicating current control state (default QoS)
  * True: Human has control (radio inputs active)
  * False: Computer has control (autonomous navigation active)
  
- /control_authority: Vector3 with detailed control status
  * x: Current authority (1=human, 0=robot)
  * y: Time since human activity
  * z: Time since auto command
  
- /rudder_sail_radio_health: Bool indicating node health status
  * true: node is healthy and hardware is accessible
  * false: node has failed or hardware is not accessible

Topics Subscribed:
- /rudder_sail_cmd: Vector3 with autonomous navigation commands (-1 to +1 range)
  * Commands from controller.py or other autonomous navigation nodes
  * Only applied when human_controlled is False

Hardware Requirements:
- argo_radio_servo_module kernel module loaded (v0.5+ with high impedance support)
- GPIO pins configured for radio input capture (PI11, PI13)
- PWM outputs configured for servo control (PI12=PWM2, PI14=PWM4)
- RC receiver connected and calibrated for 1000-2000µs pulse width range

Safety Features:
- HIGH IMPEDANCE MODE: Servo outputs default to high impedance (PWM disabled)
- Pulse width validation and clamping (900-2100µs hardware range)
- Outlier radio input filtering (500-2500µs acceptance range)
- Automatic fallback to high impedance mode on invalid inputs
- Throttled error logging to prevent log spam
- Graceful handling of hardware disconnection
- FAIL-SAFE: Radio control always works when PWM is disabled

Author: Tobi Delbruck (original pwm.py), Enhanced with control arbitration and high impedance mode
License: MIT
Version: 3.2 - Enhanced control logging, fail-safe exit handling, and human control timeout constant
"""

# Import the shared pause service
import sys
import os
sys.path.append(os.path.join(os.path.dirname(__file__), 'support'))

# Import ArgoBaseNode for standardized functionality
from argo_base_node import ArgoBaseNode

# Removed toggle_pause_service import - rudder_sail_radio node doesn't need pause functionality
import rclpy
from std_msgs.msg import Bool, Float64
from geometry_msgs.msg import Vector3
from rclpy.parameter import Parameter
from rcl_interfaces.msg import SetParametersResult

import argparse
import argcomplete
from pathlib import Path
import time
import numpy as np
import sys
import signal
import tty
import termios
import select
import cProfile
import pstats
from datetime import datetime

# --- Hardware Configuration ---
SYS_BASE_PATH = Path("/sys/kernel/argo_radio_servo")
RADIO_RUDDER_PATH = SYS_BASE_PATH / "radio_rudder_pw_us"
RADIO_SAIL_PATH = SYS_BASE_PATH / "radio_sail_pw_us"
SERVO_RUDDER_PATH = SYS_BASE_PATH / "servo_rudder_pw_us"
SERVO_SAIL_PATH = SYS_BASE_PATH / "servo_sail_pw_us"

# Kernel module enforces 900-2100µs range for servo outputs
SERVO_MIN_PW_US = 900
SERVO_MAX_PW_US = 2100

# Rudder servos (rotation reference: looking down from top of servo and rudder):
# - Radio mapping: RIGHT stick -> higher normalized command (+1).
# - Node mapping: This node maps +1 -> 2000µs (higher PW), -1 -> 1000µs (lower PW); it does NOT invert direction.
# - Rudder sign convention: -1 = left (rudder deflects to port), +1 = right (rudder to starboard)
#
# Currently installed servo (opposite-rotation):
# - Model: JR DS287MGHV (high voltage ultra speed sub-micro metal gear)
# - URL: https://www.jungheinrich.com/en/products/servos/servos-metal-gear/ds287mghv/
# - Behavior: Increasing PW -> Servo rotates CCW looking down from top of servo and rudder
# - Linkage effect: Servo CCW -> Rudder rotates CW -> Boat turns LEFT
#
# Stock (normal) DF65 rudder servo:
# - URL: https://www.dragonforce.com/products/sailboat-servos/df65-servo/
# - Behavior: Increasing PW -> Servo rotates CW
# - Linkage effect: Servo CW -> Rudder rotates CCW -> Boat turns RIGHT (intended for radio RIGHT)

# Rudder direction configuration:
# - Set the rudder channel direction (NORMAL/REVERSED) on the RC transmitter to ensure:
#   Radio RIGHT -> Boat turns RIGHT (rudder deflects to starboard).
# - This node does not perform rudder direction inversion; it always maps +1 to a higher PW.

# NOTE with replacement JR DS287MGHV servo, the servo’s mechanical response vs. PW is opposite to the stock DF65 servo.
# If the rudder direction is not set correctly on the RC transmitter and this node is not running
# (high-impedance passthrough), the boat may turn opposite to the intended direction.

# Observation (looking down from top, current JR DS287MGHV hardware):
# - Radio RIGHT -> higher PW -> servo CCW
# - Linkage: servo CCW -> rudder CW
# - Outcome: Boat turns LEFT when radio commands RIGHT (opposite of intended)
# Action required: Configure the RC transmitter rudder channel to NORMAL or REVERSED so that:
# - Radio RIGHT -> higher PW -> correct rudder deflection -> boat RIGHT (intended)

# Throttle logging for clamped values to once per minute
CLAMP_LOG_THROTTLE_S = 60.0

# Throttle logging for outlier radio PWM messages to once every 10 seconds
OUTLIER_LOG_THROTTLE_S = 60.0

# Human control timeout - seconds after last human activity before robot can take control
HUMAN_CONTROL_TIMEOUT_S = 2.0

# Default parameter values
# NOTE: These defaults are only used if the parameter is not set in the YAML configuration file.
# The launch system loads parameters from nodes/argo.yaml via --params-file,
# which overrides these defaults. To change the value, edit the YAML file or use ros2 param set.
# YAML file location: nodes/argo.yaml (rudder_sail_radio_node section)
# Human-activity deadband (normalized -1..+1). Value in argo.yaml overrides this default.
# Rudder: spring-centered at 0 — |radio_rudder| > deadband means stick deflected (human).
# Sail: TX holds last channel — only frame-to-frame sail_change > deadband counts (not |position|).
DEFAULT_DEADBAND_THRESHOLD = 0.25
HUMAN_ACTIVITY_CONSECUTIVE_READS = 2  # consecutive reads required for sail_change only (filters PWM spikes)
DEFAULT_SAFETY_MAX_SAIL = 1.0 # limit sail command magnitude (normalized); sail PWM stays 1500±500us scale
# Rudder: measured radio endpoints -> ±1 command; ±1 command -> servo output endpoints (kernel 900-2100)
DEFAULT_RADIO_RUDDER_MIN_PW = 1100
DEFAULT_RADIO_RUDDER_MAX_PW = 1900
DEFAULT_SERVO_RUDDER_MIN_PW = 900
DEFAULT_SERVO_RUDDER_MAX_PW = 2100

# Control loop timing constants
DEFAULT_CONTROL_LOOP_PERIOD = 0.05  # 20 Hz for responsive control (active)
DEFAULT_CONTROL_LOOP_PERIOD_IDLE = 0.20  # 5 Hz when idle (reduces executor overhead)
DEFAULT_STATUS_PERIOD = 0.1  # 10 Hz status updates (active)
DEFAULT_STATUS_PERIOD_IDLE = 1.0  # 1 Hz when idle (reduces executor overhead)

# Test mode configuration
TEST_MIN_PW = 900
TEST_MAX_PW = 2100
TEST_STEP = 100
TEST_DELAY_S = 0.5
TEST_DEFAULT_PW = 1500


def pw_us_to_cmd_scaled(pw_us: float, min_pw: float, max_pw: float) -> float:
    """Map pulse width (us) to normalized command in [-1, +1] using calibrated endpoints."""
    min_pw = float(min_pw)
    max_pw = float(max_pw)
    if max_pw <= min_pw:
        return 0.0
    center = (min_pw + max_pw) / 2.0
    half = (max_pw - min_pw) / 2.0
    pw_us = max(min_pw, min(max_pw, float(pw_us)))
    return (pw_us - center) / half


def cmd_to_pw_us_scaled(cmd: float, min_pw: float, max_pw: float) -> int:
    """Map normalized command [-1, +1] to pulse width (us) using calibrated endpoints."""
    min_pw = float(min_pw)
    max_pw = float(max_pw)
    if max_pw <= min_pw:
        return int((min_pw + max_pw) / 2.0)
    center = (min_pw + max_pw) / 2.0
    half = (max_pw - min_pw) / 2.0
    cmd = max(-1.0, min(1.0, float(cmd)))
    return int(center + half * cmd)


def cmd_to_pw_us(cmd: float, max_cmd: float = 1.0) -> int:
    """Sail (and legacy): 1500us center, 500us per unit; max_cmd clips normalized command."""
    cmd = max(-max_cmd, min(max_cmd, cmd))
    return int(1500 + 500 * cmd)


def pw_us_to_cmd(pw_us: float) -> float:
    """Sail (and legacy): standard 1000-2000us RC scale to [-1, +1]."""
    pw_us = max(1000.0, min(2000.0, float(pw_us)))
    return (pw_us - 1500.0) / 500.0

# Test mode helper functions


def get_initial_pw_test(path: Path) -> int:
    """Reads the initial pulse width from a sysfs file, or returns a default."""
    try:
        return int(path.read_text().strip())
    except (IOError, ValueError, FileNotFoundError):
        print(
            f"Warning: Could not read {path}, using default {TEST_DEFAULT_PW} us.", file=sys.stderr)
        return TEST_DEFAULT_PW


def read_sysfs_pw_test(path: Path) -> str:
    """Reads a pulse width from a sysfs file for display."""
    try:
        return path.read_text().strip()
    except (IOError, FileNotFoundError):
        return "N/A"


def write_sysfs_pw_test(path: Path, value: int):
    """Writes a pulse width to a sysfs file for test mode."""
    # Apply same clamping as normal mode
    value = max(SERVO_MIN_PW_US, min(SERVO_MAX_PW_US, value))
    try:
        path.write_text(str(value))
    except IOError as e:
        print(f"\nError writing to {path}: {e}", file=sys.stderr)


def display_test_status(rudder_pw: int, sail_pw: int, paused: bool):
    """Clears the screen and displays the current test status."""
    # ANSI escape code to clear screen and move cursor to top-left
    print("\033[H\033[J", end="")

    print("--- Radio Control Input Pulse Widths ---")
    print(f"Radio Rudder: {read_sysfs_pw_test(RADIO_RUDDER_PATH)} us")
    print(f"Radio Sail:   {read_sysfs_pw_test(RADIO_SAIL_PATH)} us")
    print("----------------------------------------")
    print("--- Servo Motor Output Pulse Widths (Sweeping) ---")
    print(f"Rudder (PWM2): {rudder_pw} us")
    print(f"Sail (PWM4):   {sail_pw} us")
    print("--------------------------------------------------")
    if paused:
        print("STATUS: PAUSED (Press Spacebar to RESUME)")
    else:
        print("STATUS: RUNNING (Press Spacebar to PAUSE)")
    sys.stdout.flush()


def get_key_non_blocking() -> str | None:
    """Reads a single key press without blocking. Returns None if no key is pressed."""
    if select.select([sys.stdin], [], [], 0) == ([sys.stdin], [], []):
        return sys.stdin.read(1)
    return None


def get_key_blocking() -> str:
    """Reads a single key press, blocking until one is received."""
    return sys.stdin.read(1)


def run_test_mode():
    """Runs the PWM test mode - sweeps servo outputs and displays radio inputs."""
    # Check if sysfs path exists for better error reporting
    if not SYS_BASE_PATH.is_dir():
        print(f"Error: Sysfs path {SYS_BASE_PATH} not found.", file=sys.stderr)
        print("Is the 'argo_radio_servo_module' kernel module loaded?", file=sys.stderr)
        sys.exit(1)

    # Initialize state variables
    current_rudder_pw = get_initial_pw_test(SERVO_RUDDER_PATH)
    current_sail_pw = get_initial_pw_test(SERVO_SAIL_PATH)
    direction_rudder = 1  # 1 for increasing, -1 for decreasing
    direction_sail = 1
    paused = False

    print("Starting Argo Radio Servo PWM Test Mode...")
    print("Monitoring input pulse widths and sweeping output servo positions.")
    print("Press Spacebar to PAUSE/RESUME. Press Ctrl+C to STOP.")
    time.sleep(1.5)  # Give user time to read the intro message

    # Terminal Setup
    # Save original terminal settings to restore them on exit
    old_settings = termios.tcgetattr(sys.stdin)
    try:
        # Set terminal to "cbreak" mode to read keys instantly without requiring Enter
        tty.setcbreak(sys.stdin.fileno())

        # Main Loop
        while True:
            display_test_status(current_rudder_pw, current_sail_pw, paused)

            # Handle Input for Pause/Resume
            key_pressed = get_key_non_blocking()

            if key_pressed == ' ':
                paused = not paused
                # Update status immediately
                display_test_status(current_rudder_pw, current_sail_pw, paused)

                if paused:
                    print("\nPAUSED. Press Spacebar to RESUME...")
                    sys.stdout.flush()
                    # When paused, enter a blocking loop that waits *only* for a spacebar.
                    while True:
                        key_to_resume = get_key_blocking()
                        if key_to_resume == ' ':
                            paused = not paused
                            display_test_status(
                                current_rudder_pw, current_sail_pw, paused)
                            break  # Exit this inner blocking loop

            if not paused:
                # Update Rudder (PWM2) Pulse Width
                current_rudder_pw += direction_rudder * TEST_STEP
                if current_rudder_pw > TEST_MAX_PW:
                    current_rudder_pw = TEST_MAX_PW
                    direction_rudder = -1
                elif current_rudder_pw < TEST_MIN_PW:
                    current_rudder_pw = TEST_MIN_PW
                    direction_rudder = 1
                write_sysfs_pw_test(SERVO_RUDDER_PATH, current_rudder_pw)

                # Update Sail (PWM4) Pulse Width
                current_sail_pw += direction_sail * TEST_STEP
                if current_sail_pw > TEST_MAX_PW:
                    current_sail_pw = TEST_MAX_PW
                    direction_sail = -1
                elif current_sail_pw < TEST_MIN_PW:
                    current_sail_pw = TEST_MIN_PW
                    direction_sail = 1
                write_sysfs_pw_test(SERVO_SAIL_PATH, current_sail_pw)

            time.sleep(TEST_DELAY_S)

    except KeyboardInterrupt:
        print("\nCtrl+C pressed. Exiting test mode.")
    finally:
        # CRITICAL: Release servo pins before exiting (set to high impedance mode)
        try:
            if SERVO_RUDDER_PATH.exists():
                SERVO_RUDDER_PATH.write_text("0")
            if SERVO_SAIL_PATH.exists():
                SERVO_SAIL_PATH.write_text("0")
            print("Servo outputs set to HIGH IMPEDANCE mode (radio control active)")
        except Exception as e:
            print(f"Warning: Could not set servos to high impedance mode: {e}", file=sys.stderr)
        
        # Restore Terminal
        # This block ensures terminal settings are always restored
        termios.tcsetattr(sys.stdin, termios.TCSADRAIN, old_settings)
        print("Terminal settings restored.")
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

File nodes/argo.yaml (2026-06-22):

# Centralized configuration file for all Argo nodes
# (there are a few other config files in the nodes directory, but this is the main one, see also README.md)

# NOTE code should use ruamel for yaml parsing, not standard yaml library, to preserve comments and ordering
# Global parameters (applied to all nodes)
# The /** wildcard is ROS2 parameter syntax that applies these parameters to ALL nodes
/**:
  ros__parameters:
    # Map configuration (used by sailing_area_publisher, argo_transform_publisher, controllers)
    # See https://www.google.com/maps/d/ for the source maps. See docs/README-adding-sailing-maps.md for more information.
    geofence_map_name: Argo Irchel North pond sailing area  # Argo Irchel pond sailing area | Argo Pool Hotel dek Pini | behind INI | Hotel dei Pini | Hotel dei Pini close to shore | Risi
    gps_spike_max_speed_mps: 3.0  # argo_transform_publisher: reject /fix jumps implying speed above this (m/s)
    # Controller parameters (used by controller.py and crosser controller)
    p_heading_gain: 0.8  # Proportional gain for heading control (P controller, can be extended to PID)
    min_rudder_near_boundary: 0.5  # Minimum rudder command when close to boundary (0.0-1.0)
    boundary_emergency_threshold: 3.0  # Meters from boundary for emergency turn
    turn_rudder_gain_multiplier: 2.0  # Multiplier for rudder gain during turns (more aggressive control)
    argo:
      mode: autonomous  # NOTE: Currently unused - launch mode controlled via launch argument (normal/simulation)
    # Simulation parameters (shared across simulator bridge, transform publisher, and visualization)
    # These are accessible to all nodes via the simulation.* namespace
    simulation:
      publish_rate: 2.0         # Standard publishing rate for sensors, transforms, and visualization (Hz)
      simulation_rate: 10.0     # Simulation step rate (Hz) - higher than publish_rate for accurate physics
      heading_trail_limit: 50  # Number (roughly) of historical heading markers to display in visualization
      grounding_behavior: reset # Behavior on grounding in local simulation: reset|terminate|continue
      # Sensor noise modeling for sim-to-real gap reduction
      # Set all noise parameters to 0.0 to disable noise (perfect sensors)
      sensor_noise:
        enabled: true  # Master switch for all sensor noise (set to true for realistic simulation)
        # Wind sensor (anemometer) noise parameters
        wind:
          use_apparent_wind: false  # If true, simulate apparent wind (true_wind - boat_velocity), if false use true wind
          angle_noise_stddev: 5.0   # Standard deviation of wind angle noise (degrees)
          angle_bias: 0.0           # Constant bias/offset in wind angle (degrees)
          speed_noise_stddev: 0.5   # Standard deviation of wind speed noise (m/s)
          speed_bias: 0.0           # Constant bias/offset in wind speed (m/s)
          update_rate: 4.0          # Sensor update rate (Hz) - real anemometer typically 1-10 Hz
          dropout_probability: 0.0  # Probability of sensor dropout per update (0.0-1.0)
          dropout_duration: 1.0     # Duration of dropout events (seconds)
        # Compass/IMU noise parameters
        compass:
          heading_noise_stddev: 2.0  # Standard deviation of heading noise (degrees)
          heading_bias: 0.0          # Constant bias/offset in heading (degrees) - simulates miscalibration
          heading_drift_rate: 0.1    # Heading drift rate (degrees/minute) - simulates gyro drift
          update_rate: 10.0          # Sensor update rate (Hz)
          magnetic_interference_stddev: 5.0  # Additional noise near metal/electronics (degrees)
        # GPS noise parameters
        # Values based on analysis of pond recording (argo_20251117_114846 first irchel pond in rain)
        gps:
          position_noise_stddev: 0.1  # Standard deviation of position noise (meters) - measured: 0.51m from pond recording
          cog_noise_stddev: 1.0       # Course over ground noise (degrees) - measured: 44.64° at low speeds, using conservative value
          sog_noise_stddev: 0.005       # Speed over ground noise (m/s) - measured: 0.156 m/s from pond recording
          update_rate: 0.2            # GPS update rate (Hz) - measured: ~0.2 Hz (1/5 Hz) from pond recording, critical for sim2real gap
          noise_time_constant: 10.0    # Time constant for noise filtering (seconds) - measured: 3.01s from pond recording
          dropout_probability: 0.0    # Probability of GPS fix loss per update
          dropout_duration: 2.0       # Duration of GPS dropout (seconds)
        # IMU accelerometer/gyro noise (for roll/pitch)
        imu:
          accel_noise_stddev: 0.1     # Accelerometer noise (m/s²)
          gyro_noise_stddev: 0.05     # Gyroscope noise (rad/s)
          update_rate: 100.0          # IMU update rate (Hz) - typically 50-400 Hz
        # Sensor latency (time delays)
        latency:
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

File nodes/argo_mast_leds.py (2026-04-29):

#!/usr/bin/env python
# PYTHON_ARGCOMPLETE_OK
# ROS2 Mast LED Controller Node - PCA9632 RGBW LED Driver

# This ROS2 node controls the PCA9632 4-bit I2C LED driver (NXP) located on the same
# PCB as the wind sensor. The LED controller is used to provide visual status on the mast.
#
# Hardware Setup:
# - Uses TWI2 on pins 27/28 (same electrical bus as wind sensor)
#   for electrical isolation of the LED controller in case of short circuit from the mast and salt water intrusion.
# - PCA9632 individual address 0x62 (hardware pins A1 A0; 0x70 is LED All Call, not used here)
# - Four LED channels: Red, Green, Blue, White (RGBW) via LED0-LED3
# - Resolve Linux adapter: "ls /sys/devices/platform/soc*/5002800.i2c/i2c-*"
# - Run "i2cdetect -y <resolved_bus_index>" to verify: expect 0x62 (individual) and 0x70 (All Call) for PCA9632
#
# Features:
# - Four individual subscriptions (one per color channel: R, G, B, W)
# - One combined 4-component subscription for synchronized RGBW control
# - Power button RGB mirroring: mirrors RGB channels from power button LEDs
# - Individual brightness mode: 8-bit PWM per channel (1.5625 kHz)
# - Normalized brightness (0.0-1.0) converted to 8-bit (0-255) for hardware
# - Automatic I2C error recovery with health monitoring
#
# Topics Subscribed:
# /mastled_r (std_msgs/Float32):
#   Red channel brightness (0.0-1.0, where 1.0 = maximum brightness)
# /mastled_g (std_msgs/Float32):
#   Green channel brightness (0.0-1.0)
# /mastled_b (std_msgs/Float32):
#   Blue channel brightness (0.0-1.0)
# /mastled_w (std_msgs/Float32):
#   White channel brightness (0.0-1.0)
# /mastled_rgbw (std_msgs/Float32MultiArray):
#   Combined RGBW control (data array with 4 elements: [R, G, B, W] as Float32 0.0-1.0)
# /argo/power_button/rgb (geometry_msgs/Vector3):
#   Power button RGB mirroring (x=red, y=green, z=blue as 0.0-1.0)
#   White channel is not affected by power button mirroring
#
# Command line options:
# --debug: Enable debug logging of LED values and I2C operations
# --diagnostic: Print comprehensive device diagnostics on startup (MODE1, LEDOUT, PWM, etc.)

# Import path setup (must be before other imports)
import sys
import os
sys.path.append(os.path.join(os.path.dirname(__file__), 'support'))

# Standard library imports
import time
import argparse
import glob
import argcomplete
from typing import Optional

# ROS2 imports
import rclpy
from rclpy.executors import ExternalShutdownException
from rclpy.logging import LoggingSeverity
from rclpy.qos import QoSProfile, ReliabilityPolicy, HistoryPolicy
from std_msgs.msg import Bool, Float32, Float32MultiArray, String
from geometry_msgs.msg import Vector3

# I2C communication
import smbus

# Import ArgoBaseNode for standardized functionality
from argo_base_node import ArgoBaseNode

# ============================================================================
# Constants - PCA9632 Configuration
# Reference: NXP PCA9632 datasheet (Table 6 Register summary, Section 7.3)
# ============================================================================

# I2C Configuration
# Mast LED controller is on TWI2 (pins 27/28: PI10/PI9). The Linux adapter
# index can vary by image/kernel (often i2c-4 on Orange Pi 6.1 images).
TWI2_CONTROLLER_BASENAME = "5002800.i2c"
TWI2_DEFAULT_LINUX_BUS = 4
# 7-bit individual address (hardware pins A1 A0; 0x70 is LED All Call, active at power-up)
PCA9632_I2C_ADDRESS = 0x62

# PCA9632 register addresses (control byte D[3:0]; first byte after I2C addr)
REG_MODE1 = 0x00    # Mode register 1 (SLEEP bit 4; 0 = normal, 1 = low power)
REG_MODE2 = 0x01    # Mode register 2 (OUTDRV, INVRT, OCH)
REG_PWM0 = 0x02     # LED0 brightness (Red)
REG_PWM1 = 0x03     # LED1 brightness (Green)
REG_PWM2 = 0x04     # LED2 brightness (Blue)
REG_PWM3 = 0x05     # LED3 brightness (White)
REG_GRPPWM = 0x06   # Group duty cycle (unused in individual brightness mode)
REG_GRPFREQ = 0x07  # Group frequency (unused)
REG_LEDOUT = 0x08   # LED output state: LDRx 00=off, 01=on, 10=individual PWM, 11=individual+group

# MODE1: bit 4 SLEEP (1 = oscillator off). We clear SLEEP for normal operation.
MODE1_SLEEP_BIT = 0x10   # Default 1 at power-up; write 0 to wake
MODE1_NORMAL = 0x01      # SLEEP=0, oscillator on (default has ALLCALL=1, we keep 0x01)

# LEDOUT: two bits per channel. 10 = individual PWM control via PWMx register.
LDR_OFF = 0x00       # 00 - LED off
LDR_ON = 0x01        # 01 - LED fully on (no PWM)
LDR_PWM = 0x02       # 10 - Individual brightness via PWMx
LDR_PWM_GRP = 0x03   # 11 - Individual + group (unused here)
# All four channels in individual PWM: LDR3 LDR2 LDR1 LDR0 = 10 10 10 10 = 0xAA
LEDOUT_ALL_INDIVIDUAL_PWM = 0xAA

# Brightness Configuration
BRIGHTNESS_MIN = 0.0  # Minimum normalized brightness
BRIGHTNESS_MAX = 1.0  # Maximum normalized brightness
BRIGHTNESS_HW_MIN = 0  # Minimum hardware brightness (8-bit)
BRIGHTNESS_HW_MAX = 255  # Maximum hardware brightness (8-bit)

# Topic Names
TOPIC_RED = '/mastled_r'
TOPIC_GREEN = '/mastled_g'
TOPIC_BLUE = '/mastled_b'
TOPIC_WHITE = '/mastled_w'
TOPIC_RGBW = '/mastled_rgbw'
# Power button LED mirroring topic
TOPIC_POWER_BUTTON_RGB = '/argo/power_button/rgb'  # Legacy - kept for backward compatibility
TOPIC_POWER_BUTTON_PATTERN = '/argo/power_button/pattern'  # New pattern-based topic

# Battery / USB power topics (from argo_battery_water.py)
TOPIC_BATTERY_REMAINING_PCT = '/battery_remaining_pct'  # Float32 (%)
TOPIC_AC_POWER_PRESENT = '/ac_power_present'  # Bool (true when USB/AC present)

# I2C Error Recovery
I2C_RETRY_DELAY_S = 5.0  # Fast retry interval (startup + runtime) for the first window below
I2C_RECOVERY_FAST_WINDOW_S = 900.0  # 15 min at 5s cadence; then switch to 1 min retries
I2C_ERROR_LOG_THROTTLE_S = 5.0  # Maximum I2C error logging frequency in seconds
I2C_LOW_CPU_CHECK_INTERVAL_S = 60.0  # Slow retry interval after I2C_RECOVERY_FAST_WINDOW_S

# Throttled INFO logging of mast display mode (aligned with power_control pattern logging)
PATTERN_LOG_INTERVAL_S = 60.0  # Repeat same pattern at most once per minute
SOS_MIRROR_LOG_INTERVAL_S = 20.0  # SOS RGB mirror: busier signal — ~3 logs/min when unchanged

# Only keep the latest power-button mirror message — avoids processing a backlog of identical
# pattern cycles after I2C recovery (each would restart slot playback and produce mixed output).
QOS_POWER_BUTTON_MIRROR = QoSProfile(
    depth=1,
    reliability=ReliabilityPolicy.RELIABLE,
    history=HistoryPolicy.KEEP_LAST,
)

# Optional: INFO-log each *distinct* PCA9632 PWM frame sent via _update_hardware (enable for bring-up).
TRACE_I2C_LED_PWM_OUTPUT = False
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

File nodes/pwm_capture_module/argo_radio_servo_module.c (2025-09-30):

// generated with help from https://gemini.google.com/app/19c8818984b5f80c
// MODIFIED: Added high impedance mode support for servo outputs
// When 0 is written to servo control files, PWM is disabled and pins go high impedance
// This allows radio control to pass through directly to servos via resistor network
// Default state on module load: PWM disabled (high impedance) for safety
#include <linux/init.h>
#include <linux/module.h>
#include <linux/kernel.h>
#include <linux/platform_device.h> // For struct platform_device, used with device tree
#include <linux/gpio/consumer.h> // For gpiod_get_from_of_node, gpiod_to_irq, gpiod_direction_input, etc. (modern GPIO API)
#include <linux/interrupt.h>
#include <linux/hrtimer.h>
#include <linux/ktime.h>
#include <linux/sysfs.h>
#include <linux/kobject.h>
#include <linux/spinlock.h>
#include <linux/pwm.h>          // For pwm_get, pwm_config, pwm_enable/disable, pwm_put
#include <linux/err.h>

/*
 * BUILD_DATE is expected to be passed in from the Makefile, e.g.,
 *   EXTRA_CFLAGS += -DBUILD_DATE= some date string without spaces'
 */
#ifndef BUILD_DATE
#define BUILD_DATE "unknown"
#endif

// --- Device Data Structure ---
struct argo_radio_servo_data {
	struct device *dev;
	struct gpio_desc *radio_rudder_gpiod;
	int radio_rudder_irq;
	ktime_t radio_rudder_rising_ts;
	long long radio_rudder_pw_us;
	ktime_t radio_rudder_last_pulse_ts;

	struct gpio_desc *radio_sail_gpiod;
	int radio_sail_irq;
	ktime_t radio_sail_rising_ts;
	long long radio_sail_pw_us;
	ktime_t radio_sail_last_pulse_ts;

	struct pwm_device *servo_rudder_pwm;
	struct pwm_device *servo_sail_pwm;

	unsigned long current_servo_rudder_pw;
	unsigned long current_servo_sail_pw;

	struct hrtimer print_timer;
	ktime_t module_load_ts;
	struct kobject kobj;
};

// --- Common Servo/PWM Parameters ---
#define SERVO_PERIOD_NS               20000000UL // 20ms period in nanoseconds
#define SERVO_MIN_PW_NS               900000UL   // 900us minimum pulse width in nanoseconds
#define SERVO_MAX_PW_NS               2100000UL  // 2100us maximum pulse width in nanoseconds
#define NO_PULSE_TIMEOUT_NS           (1 * NSEC_PER_SEC) // 1 second in nanoseconds

// --- Shared Resources ---
static DEFINE_SPINLOCK(capture_data_lock); // Spinlock to protect measured data
static DEFINE_SPINLOCK(output_control_lock); // Spinlock to protect PWM output writes

// --- Function Prototypes ---
static int argo_radio_servo_probe(struct platform_device *pdev);
static int argo_radio_servo_remove(struct platform_device *pdev);

// --- Sysfs Function Prototypes ---
static ssize_t radio_rudder_pw_us_show(struct kobject *kobj, struct kobj_attribute *attr, char *buf);
static ssize_t radio_sail_pw_us_show(struct kobject *kobj, struct kobj_attribute *attr, char *buf);
static ssize_t servo_rudder_pw_us_show(struct kobject *kobj, struct kobj_attribute *attr, char *buf);
static ssize_t servo_rudder_pw_us_store(struct kobject *kobj, struct kobj_attribute *attr, const char *buf, size_t count);
static ssize_t servo_sail_pw_us_show(struct kobject *kobj, struct kobj_attribute *attr, char *buf);
static ssize_t servo_sail_pw_us_store(struct kobject *kobj, struct kobj_attribute *attr, const char *buf, size_t count);
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

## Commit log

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2019-02-11 added GPS message parsing with /fix and /heading topics published. Not verfieid to work yet
    [gps.py]
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2025-04-10 set CMAKE_CSS_STANDARD 11 fix launch to respawn gps.py if it dies improve gps.py with try/except etc, not sure who made these changes
    [gps.py]
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2025-05-02 many fixes to identity of pins and tomake computer feedback control of rudder work correctly
    [anem.py]
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2025-09-12 feat: Add GUI, temp monitor, and improve power control
    Adds a new interactive CLI for monitoring and controlling the Argo sailboat, providing real-time status of ROS2 nodes, service management, and recording controls.
    Introduces a new ROS2 node for monitoring system temperature, which publishes CPU temperature and sends alerts for high/critical levels with optimized data logging.
    Refactors the power control script to use a polling-only method for button detection, adds a boot delay to prevent accidental shutdowns, and updates the systemd service to run as root.
    Improves the PWM script with throttled logging for outlier values and stricter argument parsing.
    Removes the unused power_contro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
    [argo_gui.py, argo_launch.py, temp_monitor.py]
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2025-09-13 refactor: improve Makefile organization and add Python dependency management
    - Replace hardcoded I2C bus 0 with I2C_BUS_NUMBER constant in battery_water.py
    - Add comprehensive hardware documentation to top-level comments
    - Update nodes README with detailed I2C bus 0 configuration and pin assignments
    - Add install-hardware and install-all targets to main Makefile
    - Create requirements-runtime.txt with actual node dependencies
    - Add install-python-deps target for automated pip package installation
    - Rename targets for clarity: install→install-services, enable→enable-services, disable→disable-services
    - Remove unused tqdm dependency from requirements
    -- fix power_control to be argo_power_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
    [anem.py, argo_gui.py, argo_power_control.py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]
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2025-09-17 Fix desktop notification issue when service runs as root
    - Updated send_desktop_notification() to detect when running as root
    - Automatically find desktop user by parsing Xorg process ownership
    - Use sudo -u to send notifications to user's desktop session with proper DISPLAY
    - Fixes D-Bus launch errors and notification failures in systemd service
    - Maintains backward compatibility when running as regular user
    - Resolves 'Command returned non-zero exit status 1' errors in logs
    [argo_power_control.py]
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2025-09-17 Implement hardware interrupt-based GPIO monitoring with triple tap recording control
    Major improvements to power control system:
    🚀 Hardware Interrupt Monitoring:
    - Replace polling-based button monitoring (>100% CPU) with true hardware interrupts (<1% CPU)
    - Use gpiod edge-triggered interrupts for POW_BUT pin falling edge detection
    - Implement efficient select() + epoll() based event handling
    - Maintain startup safety: button held at boot won't trigger shutdown
    🎬 Triple Tap Recording Control:
    - Add 3 quick taps within 1.5s to toggle rosbag recording
    - Fix triple tap detection logic (was only detecting 2/3 taps due to premature cleanup)
    - Implement proper timing window validation with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
    [argo_power_control.py]
2025-09-17 Fix triple tap recording toggle: change power control service user to orangepi
    [argo_power_control.py]
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2025-09-19 Major cleanup and refactoring: remove desktop status system, enhance lifecycle management
    - Remove entire desktop status notification system (8 files deleted, ~900 lines)
    - argo_desktop_status.py, .sh, .desktop files
    - startup notification service and scripts
    - ARGO_DESKTOP_STATUS_README.md
    - Enhance lifecycle manager with improved node management
    - Update power control system and shutdown procedures
    - Improve monitoring scripts (memory_monitor, terminal_warning)
    - Update ROS nodes with minor fixes (anem, imu, record)
    - Refactor Makefiles and configuration files
    - Enhance foxglove setup and plotting utilities
    Net: -741 lines, cleaner architecture focused on core functionality
    [anem.py, argo_gui.py, argo_lifecycle_manager.py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]
2025-09-20 Improve status() method to show FATAL messages for dead nodes
    - Add systemd service status check alongside launch process status
    - Extract FATAL messages from systemd journal when argo-launch.service is running
    - Display concise FATAL messages directly next to stopped nodes in status output
    - Enhanced pattern matching to identify node-specific FATAL messages
    - Improved diagnostic experience by showing failure reasons immediately
    - Maintains backward compatibility with existing error message display
    [argo_lifecycle_manager.py]
2025-09-20 Fix node status detection during startup
    - Replace static sleep with active monitoring during 15s stabilization period
    - Detect and report node failures in real-time during startup
    - Fix journal output compatibility by removing carriage returns
    - Increase argo_start.sh wait time from 5s to 10s for accurate status
    - Show FATAL error messages when nodes fail during stabilization
    - Ensure 'al' command shows actual node health, not false positives
    Fixes issue where anem.py and other nodes could fail during startup
    but appear as RUNNING in status checks due to timing issues.
    [argo_lifecycle_manager.py]
2025-09-20 Add foxglove_bridge support and remove debug output
    - Add proper foxglove_bridge launch and monitoring support
    - Launch foxglove_bridge as ROS2 package via 'ros2 run foxglove_bridge foxglove_bridge'
    - Update node status detection to handle special nodes (foxglove_bridge)
    - Fix node count monitoring to include all expected nodes (9 total)
    - Remove debug output for clean production logs
    - foxglove_bridge now appears in status output as 'foxglove_bridge: 🟢 RUNNING'
    The system now properly manages all 9 nodes including the foxglove_bridge
    for visualization and monitoring capabilities.
    [argo_lifecycle_manager.py]
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2025-09-23 Add NavSatFix support to GPS node for mapping integration
    - Add pynmea2 dependency to requirements-runtime.txt for NMEA parsing
    - Enhance GPS node to publish standard NavSatFix messages on /fix topic
    - Extract altitude, position covariance, and GPS status from NMEA sentences
    - Maintain existing SOG/COG/velocity topics for backward compatibility
    - Use pip-based dependencies only, no C/C++ compilation required
    - Enable mapping visualization in Foxglove, RViz, and other ROS tools
    [gps.py]
2025-09-24 Implement QoS persistent storage and optimize lifecycle manager
    Major improvements:
    QoS Persistence Implementation:
    - Add persistent QoS (TRANSIENT_LOCAL) to all battery_water.py topics
    - Update controller.py to use persistent QoS for critical status monitoring
    - Apply persistent QoS to temp_monitor.py alert topics
    - Update rudder_sail_radio.py human_controlled topic with persistence
    - Late-joining nodes now get latest values immediately
    Lifecycle Manager Optimizations:
    - Implement parallel topic queries using ThreadPoolExecutor (60% faster)
    - Replace slow sequential topic calls with 5 simultaneous requests
    - Remove redundant LAUNCH PROCESS status line
    - Rename SYSTEMD SERVICE to LAUNCH SE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
    [argo.yaml, argo_lifecycle_manager.py, controller.py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]
2025-09-24 Fix node shutdown issues and lifecycle manager restart logic
    - Fix pwm.py indentation error preventing startup
    - Add ExternalShutdownException handling to all nodes
    - Fix controller.py RCLError during shutdown
    - Remove automatic node restart from lifecycle manager
    - Change systemd service to Restart=no for debugging
    - Preserve node failures in journal for debugging
    [anem.py, argo_lifecycle_manager.py, controller.py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]
2025-09-25 refactor: Remove obsolete argo_status_check.py and consolidate status system
    - Remove argo_status_check.py (obsolete status checking system)
    - Update all dependencies to use argo_lifecycle_manager.py as single source of truth
    - Add timestamp update functionality to lifecycle manager status command
    - Update .bashrc functions:
    - argo_status() now uses lifecycle manager
    - argo_quick_timer() reimplemented with lifecycle manager integration
    - argo_status_check() deprecated with warning message
    - Update GUI systems:
    - argo_gui.py now uses lifecycle manager for status output
    - argo_status_gui.py handles missing obsolete module gracefully
    - argo_status_gui.sh updated with flexible depend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
    [argo_gui.py, argo_lifecycle_manager.py]
2025-09-25 Refactor: Combine PWM hardware interface into rudder_sail_radio.py
    - Delete nodes/pwm.py (490 lines) and integrate functionality into rudder_sail_radio.py
    - Unified hardware interface and control arbitration in single node
    - Direct sysfs integration with argo_radio_servo_module kernel module
    - Combined radio input capture, normalization, and servo output control
    - Maintained all original PWM functionality: pulse width conversion, validation, clamping
    - Enhanced with intelligent control arbitration and safety limits
    - Persistent QoS for critical control status (human_controlled topic)
    - High-frequency control loop (20Hz) for responsive arbitration
    - Comprehensive error handling and throttled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
    [rudder_sail_radio.py]
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2025-09-25 fix: Add ROS2 environment sourcing to ros2 commands in argo_gui.py
    - Fix 'No such file or directory: ros2' error by wrapping ros2 commands with bash environment setup
    - Update ros2 service list calls to use 'bash -c "source /opt/ros/humble/setup.bash && ros2 service list"'
    - Ensures ROS2 environment is properly sourced when GUI calls ros2 commands
    - Resolves status check failures in the GUI interface
    [argo_gui.py]
2025-09-25 fix: Increase timeout for ROS2 service list commands in argo_gui.py
    - Increase timeout from 3 seconds to 10 seconds for ros2 service list commands
    - ROS2 service list takes ~2.9 seconds to complete, causing timeouts with 3s limit
    - Resolves 'Command timed out after 3 seconds' errors in GUI status checks
    - GUI now displays full status information without timeout issues
    [argo_gui.py]
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2025-09-28 feat(simulation): Improve simulation workflow and add GPS topics
    Refactors the simulation launch process into distinct local and remote commands. Automates the remote simulation setup, including SSH tunneling and remote process management. Adds missing GPS topics (/fix, /gps_num_satellites, /gps_data) to the unified simulator bridge to provide complete data for Foxglove map visualization.
    [argo_lifecycle_manager.py, argo_unified_simulator_bridge.py]
2025-09-29 Fix simulator bridge keyboard control and add control arbitration
    - Fix rudder/sail control getting stuck at +0.125 due to boat state overriding keyboard values
    - Add colored logging with icons for different log levels (error, warning, info, debug, success)
    - Implement control arbitration logic to simulate rudder_sail_radio.py functionality
    - Add human activity detection based on keyboard input changes
    - Publish /human_controlled and /control_authority topics for proper control status
    - Fix last_cmd timing to show correct time since last human activity
    - Improve terminal restoration with better error handling for curses cleanup
    - Add proper spacing in control window to prevent text wrapping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
    [argo_lifecycle_manager.py, argo_unified_simulator_bridge.py, load_config.py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]
2025-09-29 Restore PWM test mode functionality to rudder_sail_radio.py
    - Add missing imports: tty, termios, select for terminal control
    - Restore test mode constants: TEST_MIN_PW, TEST_MAX_PW, TEST_STEP, TEST_DELAY_S
    - Implement comprehensive test mode functions:
    * run_test_mode(): Main test loop with servo sweeping
    * display_test_status(): Real-time screen updates with radio/servo pulse widths
    * get_key_non_blocking(), get_key_blocking(): Keyboard input handling
    * write_sysfs_pw_test(), read_sysfs_pw_test(): Test-specific sysfs operations
    - Add --test command line argument for standalone test mode operation
    - Enhanced help documentation with TEST MODE section
    - Maintains all original test mod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
    [rudder_sail_radio.py]
2025-09-30 feat: Add comprehensive high impedance safety mode documentation
    - Document high impedance initialization in argo_radio_servo_probe()
    - Add detailed safety documentation for set_servo_high_impedance() function
    - Document critical PWM disable steps for fail-safe operation
    - Update README.md with accurate pin definitions and high impedance usage
    - Update rudder_sail_radio.py with high impedance mode support (v3.1)
    - Add comprehensive Cursor Rules for radio/servo control system:
    * argo-radio-servo-control.mdc (always applied)
    * argo-hardware-safety.mdc (hardware safety patterns)
    * argo-kernel-module-development.mdc (kernel dev patterns)
    * argo-ros2-control-patterns.mdc (ROS2 control pat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
    [argo_radio_servo_module.c, rudder_sail_radio.py]
2025-09-30 Enhanced rudder_sail_radio.py with improved control logging and fail-safe exit handling
    - Add HUMAN_CONTROL_TIMEOUT_S constant for better maintainability
    - Enhanced control authority logging with detailed transition reasons:
    * Human takeover: Shows activity timing and previous mode duration
    * Robot takeover: Shows timeout details and autonomous command status
    * Includes contextual information (autonomous_commands_active, autonomous_standby_mode, no_autonomous_controller)
    - Comprehensive fail-safe exit handling:
    * Signal handlers for SIGTERM/SIGINT with graceful shutdown
    * atexit registration for Python exit cleanup
    * destroy_node override for ROS2 node cleanup
    * Enhanced main f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
    [rudder_sail_radio.py]
2025-09-30 Fix anemometer sensor detection for SDP3x sensors
    - Replace read_byte() with write_i2c_block_data() for sensor detection
    - SDP3x sensors don't respond to simple read_byte() commands
    - Use safe stop measurement command (0x3F, 0xF9) for detection test
    - All three sensors (0x21, 0x22, 0x23) now detected correctly
    - Verified sensor data reading works properly at 10Hz
    [anem.py]
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2025-09-30 Improve anemometer node with CRC validation and simplified architecture
    - Add CRC-8 checksum validation for SDP3x sensor data integrity
    - Implement throttled CRC error logging (max 1Hz) to prevent log spam
    - Remove complex threading and sample averaging (sensor provides averaging)
    - Increase publishing rate from 1Hz to 10Hz for better responsiveness
    - Simplify architecture: direct sensor reading without buffering
    - Reduce CPU usage by ~65% in normal mode (7.7% vs 20-27% debug mode)
    - Maintain excellent publishing rate consistency (9.98Hz)
    - Update documentation to reflect new features and configuration
    Performance improvements:
    - CPU usage: 7.7% (normal) vs 20-27% (debug mode)
    - Publishing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
    [anem.py]
2025-10-01 Fix logging system: move to persistent storage and add log rotation support
    - Move all monitoring scripts from /var/log/persistent/ (ZRAM) to /var/log.hdd/persistent/ (persistent storage)
    - Fix log rotation handling: scripts now re-evaluate date on each iteration to handle midnight rotation
    - Update thermal-monitor.sh, memory-monitor.sh, cursor-monitor.sh, oom-detector.sh
    - Update systemd services: persistent-dmesg.service, orangepi-monitor.service, crash-dump.service
    - Update Argo lifecycle manager to read CPU temperature from thermal log file (faster than sensors command)
    - Add -f/--force option to argo_quick_timer() for debugging
    - Remove old /var/log/persistent/ directory to free ZRAM sp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
    [controller.py]
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2025-10-04 Fix health status toggling in rudder_sail_radio.py
    - Remove duplicate health status setting in publish_status() to prevent race condition
    - Centralize health management in read_radio_inputs() only
    - Add detailed failure reason logging for better diagnostics
    - Health status now shows specific cause when radio transmitter is off
    - Prevents toggling between HEALTHY/FAILED states when radio is disconnected
    [rudder_sail_radio.py]
2025-10-04 Add power control service status to lifecycle manager
    - Add argo_power_control.service status check in status() method
    - Display power control status before launch service status
    - Use consistent formatting with ⚡ POWER CONTROL emoji
    - Follows same error handling pattern as launch service check
    [argo_lifecycle_manager.py]
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2025-10-05 Implement integrated battery monitoring with CSV logging and plotting
    Major Changes:
    - Integrate battery monitoring directly into battery_water.py ROS2 node
    - Add CSV logging functionality with 30-second intervals
    - Create comprehensive plotting script for battery voltage decay analysis
    - Remove separate battery-monitor systemd service (eliminates ROS2 service discovery issues)
    Battery Monitoring Features:
    - Automatic CSV file creation in /var/log.hdd/persistent/
    - Logs all sensor data: voltage, percentage, saltwater, current, temperature, humidity
    - Includes alert status and health information
    - Date-stamped files (battery-monitor-YYYYMMDD.csv)
    Plotting Script Features:
    - Auto-detects lat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
    [anem-measurement-20251001_162926.csv, anem-measurement-20251002_121234.csv, naca0015.csv]
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2025-10-06 Improve anemometer node resilience for transient I2C failures
    - Replace sys.exit(1) on IOError with graceful error handling
    - Add node health tracking with state-based frequency adaptation
    - Switch to 1Hz retry mode during I2C failures, recover to 3Hz normal operation
    - Add /anem_health topic for health status monitoring (published only on state changes)
    - Implement automatic recovery detection when I2C communication is restored
    - Add throttled error logging to prevent log spam
    - Publish health=false on node shutdown for proper cleanup
    This makes the anemometer node highly resilient to transient I2C cabling issues
    and noise while maintaining data integrity through CRC validation.
    [anem.py]
2025-10-06 Fix recording state synchronization and 'already in progress' handling
    - Handle 'recording already in progress' case properly:
    * Detect when recording is already active via service response
    * Update internal state to match reality instead of treating as error
    * Send appropriate desktop notification to user
    * Return success instead of error for this case
    - Add periodic state synchronization:
    * Query actual recording status every 30 seconds
    * Update internal state if recording status changes externally
    * Log state changes for debugging
    - Improve state management:
    * Initialize recording_active early for test mode compatibility
    * Enhanced logging for state changes and sync op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
    [argo_power_control.py]
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2025-10-06 Fix anemometer I2C recovery mechanism
    - Fixed recovery check placement: now called even when no valid samples
    - Added proactive recovery logic: triggers after 5s in retry mode
    - Implemented proper sensor re-initialization with setup_sensors()
    - Added two-tier recovery: normal setup first, then soft reset
    - Added recovery attempt tracking to prevent spam
    - Recovery now works correctly when I2C cable is disconnected/reconnected
    The node now automatically detects I2C failures, attempts recovery,
    re-initializes sensors with continuous measurement commands, and
    resumes normal 3Hz operation when communication is restored.
    [anem.py]
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2025-10-06 Add critical battery monitoring and failsafe shutdown
    - Add critical battery threshold (6.5V) monitoring to power control service
    - Implement 30-second battery monitoring timer with ROS2 service calls
    - Add critical battery halt sequence with flag file creation
    - Update shutdown hook to preserve power relay during critical battery halt
    - Add test mode support for critical battery simulation
    - Integrate with existing battery_water service for voltage data
    Features:
    - Independent monitoring thread in power control service
    - Critical battery flag file (/tmp/argo_critical_battery) for shutdown hook
    - Desktop notifications and wall messages for critical battery events
    - Graceful fallback when ba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
    [argo_power_control.py]
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2025-10-08 Fix controller.py critical node config and exclude simulator bridge from normal mode
    [argo_lifecycle_manager.py]
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2025-10-09 Fix critical battery monitoring bug - dialog timeout now proceeds with halt
    CRITICAL BUG FIX: Last evening, battery dropped to 6V but system did not halt.
    Analysis showed the confirmation dialog timed out, which CANCELLED the halt
    instead of proceeding with it. System kept running at critical voltage.
    Primary Fix - Dialog Return Logic (argo_power_control.py):
    - Fixed show_critical_battery_confirmation_dialog() return values
    - Timeout (returncode 5) now returns False (proceed with halt)
    - Cancel button (returncode 1) returns True (user intervention)
    - Dialog failure returns False (proceed with halt - safe default)
    - Result: Timeout = automatic halt (safe for autonomous operation)
    - User can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
    [argo_power_control.py]
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2025-10-09 Add abort option for quick status check
    Allow users to press Enter during status check to skip detailed system info.
    This saves ~1.5 seconds by avoiding the slow CPU percentage measurement.
    Implementation uses select() with 0.5s timeout before the 1-second CPU check.
    Simple and non-intrusive for normal status checks.
    [argo_lifecycle_manager.py]
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2025-10-10 Add return-to-home functionality with LoRa connectivity monitoring
    Implements automatic RTH navigation when shore connection lost >120s, GPS-based bearing/distance calculation, ReturnToHomeController class, and remote command support via LoRa. Home position auto-set on first GPS fix.
    [controller.py]
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2025-10-10 CRITICAL FIX: Prevent false battery halt on invalid readings and service failures
    Fix two critical bugs that caused system to halt on non-battery issues:
    Bug 1: Invalid voltage readings triggered critical battery halt
    - Problem: 0V or invalid readings from battery service caused immediate halt
    - Root cause: Sensor errors, I2C failures, or service startup issues were
    interpreted as critical battery emergencies
    - Fix: Invalid readings (0V, <3V, >30V) now log errors but NEVER halt
    - System only halts on VALID low voltage readings (below 7.2V)
    Bug 2: Battery service unavailability triggered halt
    - Problem: If battery_water.service wasn't running, system halted after 60s
    - Root cause: Missing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
    [argo_power_control.py]
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2025-10-12 Add critical warning when I2C bus has no devices detected (prevents battery monitoring and safety halt)
    [argo_lifecycle_manager.py]
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2025-10-13 Add bash tab completion support to all Argo scripts
    Enable intelligent argument completion for all Python scripts using argcomplete.
    Completion works for both 'python3 script.py' and './script.py' invocations.
    Changes:
    - Add PYTHON_ARGCOMPLETE_OK marker to 11 Python scripts
    - Add argcomplete integration (import + autocomplete call) to all scripts
    - Update dotfiles/.bash_completion_argo for auto-setup (no sudo needed)
    - Fix scripts/add_argcomplete_to_script.sh to handle parse_args() with parameters
    - Add comprehensive dotfiles/README.md with usage examples
    Scripts with completion enabled:
    - launch/argo_lifecycle_manager.py (commands: run, stop, status, simulate_local, etc.)
    - power_control/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
    [anem.py, argo_lifecycle_manager.py, argo_power_control.py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]
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
